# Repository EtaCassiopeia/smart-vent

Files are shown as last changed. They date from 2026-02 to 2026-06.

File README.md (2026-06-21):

# smart-vent

Per-room HVAC vent control. Each vent has a small XIAO ESP32-C6 board driving an SG90
hobby servo that opens or closes a louver. The board joins a Thread mesh hosted by a
Raspberry Pi and exposes itself as a Matter **Window Covering** device. Home Assistant
runs on the same Pi and is the user-facing controller — you toggle the vent in the HA UI
or in a HA automation, and the command travels over Matter-over-Thread to the device,
which moves the servo.

The project is **Matter-over-Thread only**. There is no Wi-Fi path on the device, and no
cloud dependency. The Pi is the entire backend.

## Hardware

| Role | Part | Notes |
|---|---|---|
| Hub | Raspberry Pi (any model with USB) | Runs three Docker containers: OTBR, matter-server, Home Assistant |
| Thread radio | SMLIGHT SLZB-07 USB dongle | CP210x USB-UART (`10c4:ea60`), enumerates as `/dev/ttyUSB0`. Used by OTBR as the Thread Radio Co-Processor |
| Vent MCU | Seeed XIAO ESP32-C6 | RISC-V chip with built-in 802.15.4 and BLE radios. Enumerates as `/dev/ttyACM0` (`303a:1001`) when plugged **directly** into the Pi — not through a USB hub |
| Actuator | SG90 servo | Signal on GPIO2 (XIAO D2 pin). 90° = vent closed, 180° = vent open |

## Architecture at a glance

```
   ┌─────────────────────── Raspberry Pi ──────────────────────────┐
   │                                                                │
   │  Home Assistant ── (WebSocket) ──► matter-server               │
   │       (:8123)                       (:5580)                    │
   │                                        │ BLE pairing           │
   │                                        ▼                       │
   │                                     BlueZ ─── (host BT)        │
   │                                        │                       │
   │                                        │ Matter ops over IPv6  │
   │                                        ▼                       │
   │                                     OTBR (OpenThread Border    │
   │                                           Router container)    │
   │                                        │                       │
   │                                        │ Thread (802.15.4)     │
   └────────────────────────────────────────┼───────────────────────┘
                                            │  ▲
                                  via SLZB-07 USB dongle
                                            │  │
                              ┌─────────────▼──┴────────────┐
                              │   XIAO ESP32-C6 (vent N)    │
                              │   Rust firmware + esp-matter│
                              │   GPIO2 ─► SG90 servo       │
                              └─────────────────────────────┘
```

## Where to look

- **[docs/handbook.md](docs/handbook.md)** — what the system is, how it works, why
  it's built the way it is. Read this top-to-bottom once. Covers Matter, Thread,
  the Pi services, the firmware internals, what happens during commissioning and
  on every replug.
- **[docs/runbook.md](docs/runbook.md)** — step-by-step procedures for **developers**.
  How to set up the Pi from scratch, build the firmware, flash a new vent, commission
  it via HA, assign it to a room. Plus a symptom-driven troubleshooting matrix.
- **[docs/provider-runbook.md](docs/provider-runbook.md)** — step-by-step for
  **providers** assembling kits to ship to clients. Uses the
  `smart-vent-provision` CLI end-to-end: bake the SD card, flash + capture N
  vents, print stickers + quick-start, pack and ship. No source builds.
- **[docs/mobile-api.md](docs/mobile-api.md)** — API contract the smart-vent mobile
  app builds against (matter-server WS, HA REST, mDNS).
- **[docs/mobile-app-spec.md](docs/mobile-app-spec.md)** — screen-by-screen spec
  the Flutter team works from.

## Repo layout

```
firmware/
  vent-controller/                 ESP32-C6 firmware (Rust + ESP-IDF v5.2.3)
    src/                           Rust modules: main, matter, servo, state, identity, ...
    components/esp_matter_bridge/  C++ shim over esp-matter SDK
    sdkconfig.defaults             Non-default ESP-IDF kconfig
    partitions.csv                 nvs / phy_init / 3 MB factory app layout
  shared-protocol/                 vent-protocol crate (CBOR types, angle constants)
docs/
  handbook.md                      Conceptual reference
  runbook.md                       Step-by-step procedures
homeassistant/                     Example HA configs (scripts, automations,
                                   schedule helpers, Lovelace dashboard) for
                                   room/floor grouping and scheduling. Copy
                                   into ~/homeassistant/. See runbook §7.5.
tools/
  scripts/                         setup_otbr.sh, setup_ha.sh — reference Pi bring-up
  qr-generator/                    Renders printable QR PNGs from the boot-logged Matter payload
```

## Status

All firmware code lives on the `feature/matter-over-thread` branch. One vent has been
fully commissioned and verified end-to-end (HA → Close button → servo turns to 90°,
HA → Open → servo turns to 180°). The same firmware image can be flashed onto any
number of XIAO ESP32-C6 boards to add more vents — see the runbook.

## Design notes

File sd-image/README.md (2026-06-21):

# SD card image bake

Workstream C of the deployment plan: bake a Raspberry Pi OS image that
contains the smart-vent runtime, the systemd units, the first-boot
wizard, and the seeded HA config — so the provider can `dd` it to an
SD card and ship.

The bake re-uses `pi/install.sh` against a Raspberry Pi OS Lite
chroot. install.sh is the single source of truth for the layout —
there is no parallel "what the SD image contains" definition.

## Layout

```
sd-image/
  config                              pi-gen build config (IMG_NAME, stage list, …)
  stage-smart-vent/
    prerun.sh                         rsync the repo into the chroot at /usr/src/smart-vent
    EXPORT_IMAGE                      marker telling pi-gen to export an .img from this stage
    00-install/
      00-run-chroot.sh                run install.sh inside the chroot
```

## How CI uses this

`.github/workflows/sd-image.yml` (added alongside this directory)
on a `hub-v*` tag or manual dispatch:

1. Checks out smart-vent at the tag.
2. Clones [pi-gen](https://github.com/RPi-Distro/pi-gen) into the runner.
3. Drops our `config` and `stage-smart-vent` into pi-gen's tree.
4. Runs pi-gen inside Docker (ARM emulation via QEMU binfmt).
5. Captures `deploy/*.img.xz` + sha256, uploads as a release asset.

Expected runtime on `ubuntu-latest`: ~30–60 min cold.

## How to bake locally (if you have ~30 min and Docker)

```bash
git clone --branch 2026-06-18-raspios-bookworm-arm64 \
  https://github.com/RPi-Distro/pi-gen
cd pi-gen
cp ../smart-vent/sd-image/config ./config
cp -r ../smart-vent/sd-image/stage-smart-vent ./
# Stage the smart-vent source where prerun.sh can find it. build-docker.sh
# only mounts the pi-gen tree into the build container, so we co-locate.
rsync -a \
  --exclude '.git/' \
  --exclude 'firmware/vent-controller/target/' \
  --exclude '**/__pycache__/' --exclude '**/.venv/' \
  ../smart-vent/ stage-smart-vent/src/
echo 'export SMART_VENT_VERSION=dev' >> config
sudo CONTINUE=1 ./build-docker.sh
ls deploy/
```

## Why pi-gen, not packer / nspawn / etc

pi-gen is the official Raspberry Pi tooling, knows the exact partition
layout / bootloader / firstrun.sh shape Pi OS expects, and is what
upstream Raspberry Pi OS releases are built with. Less surprise on
boot.

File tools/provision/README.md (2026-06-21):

# smart-vent-provision

Provider-side CLI for prepping smart-vent kits.

## Phases — separate by design

This tool is responsible for the **provider** workflow: writing firmware
to boards and gathering the artifacts needed to print stickers for each
vent. It does **not** commission anything. Commissioning (pairing a vent
to a Matter fabric and assigning it to a room) is the **client's** job,
done from the smart-vent mobile app at install time.

| Phase | Owned by | Tool | Effect |
|---|---|---|---|
| Flash | Provider | `smart-vent-provision flash` | Writes firmware to the ESP32-C6 via `espflash`. Nothing else. |
| Capture | Provider | `smart-vent-provision capture` | Reads the post-boot serial log, records each board's EUI-64 / Matter QR / pairing code into a per-kit `inventory.json`. |
| Label | Provider | `smart-vent-provision labels` | Renders an Avery 5160 sticker sheet from the inventory. Sticker goes on the physical vent. |
| Quick-start | Provider | `smart-vent-provision kit-card` | Renders the one-page card that ships in the box. |
| SD image | Provider | `smart-vent-provision image` | Pulls the hub `.img.xz` from the latest `hub-v*` GitHub release, sha256-verifies it, and `xz \| dd`s it onto the SD card. |
| **Commission** | **Client** | **smart-vent mobile app** | **Scans the sticker QR, pairs the vent into the client's HA fabric, picks the room/floor.** |

The mobile app is a separate project (Flutter, single codebase for
Android + iOS). It talks to the client's hub via `matter-server`'s
WebSocket API and HA's REST API. It is not part of this CLI.

## Install

The CLI is published as a Python wheel via the repo's release pipeline.
Until that wheel lands, install from this repo:

```bash
cd tools/provision
pip install --user -e .

# Optional dev deps for running the tests:
pip install --user -e ".[dev]"
```

External dependency: **espflash** must be on `PATH`.

```bash
cargo install espflash --version '^3'
```

## Usage

### Flash a board (just the firmware bits)

```bash
# Single board
smart-vent-provision flash

# Several in a row
smart-vent-provision flash --count 6
```

The CLI prompts you to BOOT-hold + replug, then runs espflash. Repeat
for as many boards as `--count`. No inventory is written.

### Capture a board's identity for the sticker

After flashing, power-cycle the board (NO BOOT hold) so it emits a
fresh boot banner, then:

```bash
smart-vent-provision capture --kit-id kit-acme-2026-06-001
# optional cosmetic hint (purely what gets printed on the sticker)
smart-vent-provision capture --kit-id kit-acme-2026-06-001 --label-hint 'study'
```

This reads `/dev/ttyACM0` for up to 45s, pulls the EUI-64, Matter QR
payload, and manual pairing code from the boot log, and appends to
`./kits/<kit-id>/inventory.json`.

### Flash + capture in one walk (convenience)

```bash
smart-vent-provision batch --count 6 \
  --kit-id kit-acme-2026-06-001 \
  --label-hints 'living room,living room,study,study,bedroom 1,basement'
```

Walks: BOOT-hold prompt → flash → power-cycle prompt → capture, for
each of N boards. The label-hints are purely cosmetic printed text;
they do **not** assign vents to rooms.

### Print stickers + client card

```bash
smart-vent-provision labels   --kit kit-acme-2026-06-001  # -> labels.pdf
smart-vent-provision kit-card --kit kit-acme-2026-06-001 \
  --ap-password 'changeMe' --support-contact 'help@smart-vent.example'
```

### Write the SD card

```bash
# Pulls the latest hub-v* GH release, sha256-verifies, dd's onto /dev/sdb.
sudo smart-vent-provision image --device /dev/sdb

# Pin to a specific tag instead of latest:
sudo smart-vent-provision image --device /dev/sdb --hub-tag hub-v0.1.0
```

Refuses to write to anything that isn't a whole-disk block device
(catches the common `/dev/sdb1` partition mistake) and prompts for
confirmation before clobbering the device. `--yes` skips the prompt
for automation. Needs `xz` and `dd` on `PATH` — both ship in any
Debian/Ubuntu base install.

## Inventory schema

```json
{
  "kit_id": "kit-acme-2026-06-001",
  "firmware_version": "firmware-v0.1.0",
  "hub_image_version": "",
  "vents": [
    {
      "eui64": "58:e6:c5:01:0a:dc",
      "qr": "MT:Y3.13OTB00KA0648G00",
      "manual_code": "34970112332",
      "label_hint": "study"
    }
  ]
}
```

Hand-editable. Fix typos, add cosmetic hints, reorder before printing.
`label_hint` is **just sticker text** — the client app decides the
actual room during commissioning.

## Limitations (v1)

- One board at a time. No parallel flash jig (BOOT-hold is still
  manual). Operator target: <30 s/board after the first.
- `image` subcommand (write SD card) deferred — depends on the Pi hub
  SD image, which is the next workstream.
- Per-vent unique Matter passcodes deferred to v2 (per-device factory
  NVS partitions via `mfg_tool`). v1 uses the SDK default passcode.

## Tests

```bash
pytest tools/provision/tests -q
```

No hardware needed — release fetch is mocked, label/QR rendering is
deterministic.

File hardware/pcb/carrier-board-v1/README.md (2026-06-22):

# Battery carrier board — v1 assets

Generated assets for the NiMH battery carrier PCB. See
[`docs/battery-carrier-board.md`](../../../docs/battery-carrier-board.md) for
the design writeup, BOM, layout rules, and current status (schematic
validated, footprint placement collision-checked and fixed, routing not
yet done).

**Two variants**: the status LED is optional (see the doc's §2a for the
tradeoff — locate/status feedback vs. a small continuous idle draw on the
3V3 rail plus a tighter placement). Both are generated from the same
`smart_vent_board.py`; pick whichever matches your build.

| File | What it is |
|---|---|
| `smart_vent_board.py` | Circuit as code (SKiDL). Source of truth — edit this, re-run, re-import. `python3 smart_vent_board.py` regenerates `smart_vent.net` (with LED); `SMART_VENT_LED=0 python3 smart_vent_board.py` regenerates `smart_vent_no_led.net` (without). Requires `pip install skidl`. |
| `smart_vent.net` | KiCad netlist, with-LED variant. Import via Pcbnew → File → Import → Netlist. |
| `smart_vent_no_led.net` | KiCad netlist, no-LED variant. |
| `smart_vent_floorplan.svg` | Original placement *concept* diagram (component zones, power-loop routing, ground star point). The zoning (left=signal, right=power, bottom=connectors) is still accurate; the exact part positions drawn here are not — they predate fitting real footprint sizes and were superseded by the collision-free coordinates in `kicad-project/` and `place_smart_vent.py`. Treat this SVG as illustrating the *idea*, not the final layout. |
| `place_smart_vent.py` | Run from KiCad's Pcbnew scripting console (after netlist import + footprint assignment) to auto-place all footprints per the floorplan, draw the 45×34 mm board outline, and add mounting holes. Works for either variant — it skips refs that aren't present (D1/R7/C5 on the no-LED import). |
| `smart_vent_bench_sheet.pdf` | One-page printable BOM + assembly order + smoke test, for the with-LED bench build. |
| `firmware-reference/power_indicator.rs` | Mirror of `firmware/vent-controller/src/carrier_board.rs` — the real module now lives in the crate (behind the `battery-carrier-board`/`led-indicator` Cargo features) and is the source of truth; this copy is kept for browsing without cloning the firmware build. Verified building on `riscv32imac-esp-espidf` against the crate's pinned `esp-idf-hal`; not yet called from `main()` or flashed (see #47). |
| `kicad-project/` | Placement-checked `.kicad_pcb` (zero shorts/overlaps/clearance violations, not yet routed) + `.kicad_pro` projects + DRC reports + the `nudge_apart.py` solver, for both variants — see its own README. |

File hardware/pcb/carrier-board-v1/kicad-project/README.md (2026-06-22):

# KiCad project — placement clean, NOT routed, NOT fab-ready

Two boards here, one per LED variant (see
[`docs/battery-carrier-board.md` §2a](../../../../docs/battery-carrier-board.md#2a-led-indicator-optional)
for the tradeoff):

| | With LED | Without LED |
|---|---|---|
| Board | `smart_vent_v1.kicad_pcb` | `smart_vent_v1_no_led.kicad_pcb` |
| Project | `smart_vent_v1.kicad_pro` | `smart_vent_v1_no_led.kicad_pro` |
| DRC report | `drc_report.json` | `drc_report_no_led.json` |
| Build with | `python3 build_board.py` | `SMART_VENT_LED=0 python3 build_board.py` |

Each `.kicad_pcb` has a matching `.kicad_pro` — open that (or just the
`.kicad_pcb` directly, KiCad doesn't require the project file to open a
board standalone) so the net-class trace/via widths from
[§5](../../../../docs/battery-carrier-board.md#5-board-layout-rules)
persist between sessions instead of resetting to defaults: `Default`
(signals) at 0.25mm track / 0.5mm via, `Power` (VBAT, VBAT_RAW, SERVO_VCC,
GND) at 0.9mm track / 0.6mm via. The project files were hand-built from
KiCad's blank template (`pcbnew` scripting doesn't expose project creation)
— if KiCad ever rewrites them on save, that's expected and fine.

Both were generated by `build_board.py` (run against KiCad 10.0.4's bundled
`pcbnew` Python module — see the script for how to invoke it; it bypasses
the GUI-only netlist-import step, which modern KiCad no longer exposes to
scripting). It loads real footprints from KiCad's stock libraries where one
exists, places everything at resolved, collision-free coordinates (see
below), and wires nets per `../smart_vent_board.py`'s connectivity.
**No copper has been routed on either.**

## Placement: resolved (issue #46's DRC findings are fixed)

The original floorplan (`smart_vent_floorplan.svg`) got the *zoning* right
— left=signal, right=power, bottom=connectors — but the exact coordinates
didn't account for real footprint courtyard sizes, and at actual sizes
several parts collided: the THT slide switch substitute for SW1 (10.37mm
wide — much bigger than the small SMD pushbutton the floorplan was sized
around) and the THT radial cap substitute for C2 (8.59mm round, vs. the
small SMD electrolytic originally planned) were the two biggest culprits.

`nudge_apart.py` solves this: it builds the board, finds every pair of
overlapping courtyards (using real, post-rotation courtyard geometry), and
iteratively pushes them apart along whichever axis needs the smaller move,
holding U1/J2/the left analog cluster (R4/R5/R6/C1) fixed since they had no
DRC findings. It converges to the coordinates now hardcoded in
`build_board.py`'s `PLACE` dicts. One footprint needed a manual follow-up
the solver doesn't know about: **J2** (the servo header) had its last pad
landing past the board's bottom edge entirely at its original anchor
position (the footprint's "position" is pad 1, not its geometric center —
a 3-pin 2.54mm-pitch vertical header's last pad sits 5.08mm away from that
anchor) and separately collided with **U1**'s placeholder footprint, which
is a tall thin single-column header utterly unrepresentative of the real
XIAO module's shape (see #45) — J2 ended up shifted sideways in x to clear
U1's column, then up in y to clear the board edge by the required 0.5mm.

Re-running DRC after these fixes, on both variants:

| | With LED (before → after) | Without LED (before → after) |
|---|---|---|
| Shorts | 3 → **0** | 1 → **0** |
| Clearance violations | 1 → **0** | 1 → **0** |
| Courtyard overlaps | 8 → **0** | 5 → **0** |
| Board-edge clearance | (masked by the above) → **0** | (masked by the above) → **0** |

What's left in `drc_report*.json` is purely cosmetic: silkscreen reference
labels overlapping each other or clipped by the board edge/solder mask —
normal for default-placed footprint text once parts are packed this
tightly, fixed by dragging labels in the PCB editor, not a routing or
electrical concern.

## Footprints with no exact stock match (placeholders, need sourcing — issue #45)

**C2 is resolved** — `Capacitor_SMD:CP_Elec_6.3x5.4` exists after all; the
first pass's library search missed it (it's filed under
`Capacitor_SMD.pretty`, not a separate electrolytic library). It's now the
real footprint on both boards (courtyard 9.69×7.19mm — similar area to the
THT stand-in it replaced, not smaller as originally assumed; needed one
follow-up nudge to R2 to clear a new, smaller overlap once the real shape
went in). Two placeholders remain:

| Ref | Part | Stand-in used | What's actually needed |
|---|---|---|---|
| U1 | Seeed XIAO ESP32-C6 | generic 1×7 pin header | The official Seeed XIAO footprint (KiCad's stock libraries only ship `MCU_Seeed_ESP32C3`, not the XIAO carrier module). Source from Seeed's own KiCad library or via `easyeda2kicad` against the LCSC part. Its odd placeholder shape is also why J2 needed the manual nudge above — expect to revisit J2's exact position once the real footprint lands. |
| J1 | "SM-2P" battery connector | generic 1×2 pin header | The hobby-RC "JST-SM" 2-pin plug is not a real JST series (despite the name) and isn't in KiCad's `Connector_JST.pretty` (checked `JST_PH`/`JST_VH`/`JST_GH` series specifically — none match). Needs a footprint sourced from the connector's actual datasheet/LCSC listing (e.g. via `easyeda2kicad` against a specific part number once you've picked the exact connector to buy), or substitute a connector that *is* in-library and adjust the BOM. |

## What's left (tracked in #46)

Placement is clean; routing is not done. Next: route to the five rules in
[`../../../../docs/battery-carrier-board.md` §5](../../../../docs/battery-carrier-board.md#5-board-layout-rules)
(fat traces on the servo power loop, single star ground, etc.), apply the
net classes from the `.kicad_pro` files, run DRC again (should stay clean
on the electrical/courtyard front; clean up the cosmetic silkscreen
overlaps while you're in there), then plot Gerbers per §6.

## Gerbers (pipeline validation only — see the warning in each folder)

`gerbers-unrouted-with-led/` and `gerbers-unrouted-no-led/` are committed
Gerber + drill exports of these same two boards. **Do not send these to a
fab** — there's no copper routed, even though placement is now clean. They
exist to confirm the export pipeline produces the JLCPCB-compatible layer
set documented in the main doc's §6; each folder has its own README
repeating this warning and the exact `kicad-cli` commands used to generate
it, so they're trivially reproducible rather than load-bearing artifacts.

To regenerate either (or once a board is actually routed):

```bash
kicad-cli pcb export gerbers --output <dest>/ <board>.kicad_pcb
kicad-cli pcb export drill   --output <dest>/ <board>.kicad_pcb
```

Once routing is done, replace these with the actual fab-ready output and
drop "unrouted" from the directory names.

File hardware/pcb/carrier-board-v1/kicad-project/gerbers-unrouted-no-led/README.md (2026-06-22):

# DO NOT SEND TO A FAB

These Gerbers + drill file were plotted from `../smart_vent_v1_no_led.kicad_pcb`,
which now has a collision-free placement (see issue #46 — all shorts,
clearance violations, and courtyard overlaps are resolved) but **still has
no copper routed**. They exist solely to confirm the fab-export pipeline
itself works and produces the JLCPCB-compatible layer set documented in
[`docs/battery-carrier-board.md` §6](../../../../../docs/battery-carrier-board.md#6-fab-settings-jlcpcb)
— that is the only thing they verify.

Regenerate after routing with:

```
kicad-cli pcb export gerbers --output gerbers-unrouted-no-led/ ../smart_vent_v1_no_led.kicad_pcb
kicad-cli pcb export drill   --output gerbers-unrouted-no-led/ ../smart_vent_v1_no_led.kicad_pcb
```

(swap in the routed board path once routing is done, and rename the output
directory to drop "unrouted").

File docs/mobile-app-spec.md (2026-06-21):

# smart-vent mobile app — spec

> **Status: deferred / reference only.** As of v1, smart-vent vents
> commission via the Home Assistant Companion app out of the box —
> client scans the QR sticker on each vent, picks a room, done. A
> custom branded app duplicates the HA app's commissioning flow
> without adding engineering value; the only reasons to build one
> are branding or a streamlined onboarding UX for non-technical
> clients. This document remains as the contract a future
> branded-app effort would target. The companion contract document
> [`mobile-api.md`](mobile-api.md) is useful regardless — it
> describes what any integration (custom app, automation script,
> third-party tool) would talk to.

The smart-vent mobile app, **if built**, would be the
**client-facing** half of the deployment plan (workstream 6). It
would live in a separate Flutter repo (`smart-vent-app`, not in this
repo); this document defines what it needs to do. The API contract
it would build against is in [`mobile-api.md`](mobile-api.md).

## Audience + scope

The app is for the **end client**, not the provider. The provider
uses `smart-vent-provision` to prep kits; the client uses the app
to turn a freshly delivered kit into a working installation.

The app handles three things:

1. Pair the phone to the user's hub (mDNS discovery + HA token).
2. Add each vent to the user's home: scan QR sticker, the hub
   commissions it, the user picks a room.
3. Day-2: a thin "control my vents" surface so a user can open/
   close a vent without opening HA. (HA is still available; we just
   want one-tap control for non-techy users.)

Anything more complex than that — automations, advanced configuration,
multi-user sharing — happens in HA's own app. We don't reimplement
HA.

## Why Flutter + WS-API approach

The phone **does not** run a Matter SDK. The Pi does. Concretely:

- The phone is on the home WiFi.
- The Pi has BLE and 802.15.4 radios; it's the Matter controller.
- The app sends JSON to `ws://<hub>:5580/ws` and HA's REST.

This was the major decision documented in the design plan
(workstream 6.1). The trade-off: the Pi must be within BLE range
(~10 m) of each vent during commissioning. That's fine because OTBR
needs the Pi central in the house anyway.

Flutter is the single-codebase choice (Android + iOS); no platform
forks.

## Screen-by-screen flow

### Screen 0 — Welcome / discovery

- Logo, "Get started" button.
- On tap, browse mDNS for `_smart-vent._tcp.local.`.
- If one hub found, auto-select it. If multiple, list them with
  TXT-record version. If none, "Enter hub address" manual input.
- "Where do I find this?" link → kit-card photo with the AP
  SSID/password shown.

### Screen 1 — HA token

- "We need to connect to your hub" panel.
- "Sign in to Home Assistant" button → opens HA's OAuth flow in a
  WebView at `http://<hub>:8123/auth/authorize?...`.
- On callback, store the long-lived access token in
  keychain/keystore. Verify with a `GET /api/` ping.

### Screen 2 — Home

After auth, the home screen shows:

- A list of already-commissioned vents (from `get_nodes` →
  filter for WindowCovering), grouped by HA Area.
- Per vent: name, room, current position (% open), open/close
  buttons.
- Floating "+" button → **Add a vent** (Screen 3).
- Top-right gear → settings (re-auth, change hub, factory reset).

### Screen 3 — Add a vent

- "Point at the sticker" camera viewport.
- Auto-detect Matter QR (the `MT:...` prefix). Once detected:
  vibrate, show a "Pair this vent?" confirmation with the last 4
  of the EUI (from the sticker).
- On confirm: full-screen progress card. Streams matter-server's
  WS events:
  1. "Connecting over Bluetooth…" (PASE)
  2. "Sending Thread credentials…" (push)
  3. "Confirming…" (CASE)
- On failure: show the error code from
  [`mobile-api.md`](mobile-api.md#commission_with_code) verbatim
  + a one-line plain-English explanation + "Try again" button.
- On success: → Screen 4.

### Screen 4 — Place this vent

- "Which room is this vent in?"
- Picker reads existing HA Areas. Below the picker: "+ New room"
  → name input, optional Floor picker (or "+ New floor").
- "Optional: give this vent a name" text field. Defaults to the
  next-free `<room>-vent-<n>` slot.
- Continue → calls HA WS:
  1. Create the Area + Floor if needed
  2. Set the cover entity's `area_id`
  3. Rename the entity to `cover.<room>_vent_<n>` (slugified)
- → Screen 5.

### Screen 5 — Test the vent

- "Let's make sure it works." Big "Open" + "Close" buttons.
- On tap: `device_command` to the WindowCovering cluster. Watch
  for the position attribute to update; show the new position.
- "Done" button → back to Home (Screen 2) with the new vent
  listed.

### Screen 6 — Per-vent control (from Home, tap a vent)

- Cover entity name + room.
- Big position slider (0-100%).
- "Open", "Close", "Set to 50%" quick buttons.
- "Rename" / "Move to another room" / "Remove vent" overflow menu.
- "Identify" button → calls Matter Identify cluster, vent wiggles.

### Screen 7 — Settings

- Hub: name, version (from mDNS TXT), "Switch hub" button.
- Account: HA user email, "Sign out" (clears token).
- About: app version, contract version, link to docs.
- "Factory reset" — clears the keychain entry and returns to
  Screen 0.

## State-management notes (for the implementer)

- Cache `get_nodes` for ~30s; refresh on focus.
- Stream live position updates via matter-server's subscription
  mechanism (`start_listening` then attribute-changed events) for
  the Home screen and per-vent screen.
- WS reconnection: exponential backoff, max 60s. Show a
  non-blocking "Reconnecting…" banner; don't gate the UI.
- Token refresh: HA's long-lived token doesn't expire (by design).
  No refresh dance needed.

## Branding hooks

Provider can ship a white-labeled build by overriding:

- `assets/logo.svg`
- `lib/theme.dart` — primary color, accent, dark variant
- `strings.arb` — support email, app name

These are pulled at build time from `--dart-define` flags so the
same CI workflow produces both a default build and per-provider
builds.

## Out of scope (for v1)

- Multi-fabric / Apple Home commissioning. Matter spec supports
  multi-admin handoff; we punt it to v2.
- In-app firmware updates for vents. OTA needs the Matter
  OTAProvider cluster which we don't ship yet.
- iPad / tablet-specific layouts. Phone-first for v1.
- Notifications (filter clean reminders etc.). v2 once we figure
  out a sensor strategy.

## Build + ship

- iOS: TestFlight for beta, App Store for GA. Apple developer
  account is the provider's responsibility.
- Android: GitHub Releases for `.apk` sideloads, Play Store for GA.
- Same versioning scheme as the rest of the project (`app-vX.Y.Z`).

## Contract changes

If the hub side (matter-server commands, HA WS messages, mDNS TXT
shape) needs to change in a way that breaks older app builds, the
hub bumps its `_smart-vent._tcp.local.` TXT `version` field to a
new major. The app shows a "your hub is newer than this app, please
update" screen and refuses to commission. Provider then ships an
app update.

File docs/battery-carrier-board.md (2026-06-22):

# Battery carrier board (NiMH) — design notes

> **Status: schematic/netlist validated, placement clean, board not yet
> routed.** This document covers an alternative power path for a vent:
> running off a 4-cell NiMH pack instead of USB, via a small carrier PCB.
> The circuit (parts, values, nets) is done and machine-verified;
> footprint placement has been collision-checked and fixed (zero shorts/
> overlaps/clearance violations on both variants); routing/Gerbers are
> not done. See [Current state](#current-state) for exactly what exists
> and what's left.
>
> **Two variants, pick one**: the status LED (§2a) is optional. Both a
> with-LED and a no-LED build are generated from the same source and
> tracked side by side — the no-LED variant trades away locate/status
> feedback for a lower idle power draw.

This is a variant of the wiring in [handbook.md §3](handbook.md) (XIAO +
SG90 over USB power). Use this doc instead of the handbook's wiring table when
building a battery-powered vent.

## 1. Why a carrier board, and why NiMH

The target battery is a 4.8 V, 2-cell-pack-of-2 (4-cell) **NiMH** RC pack,
1000 mAh, with an SM-2P plug. Two things made a custom PCB worth it over
hand-wiring:

- The XIAO ESP32-C6's onboard charge controller only charges a single-cell
  3.7 V **LiPo** on its `B+`/`B-` pads (4.2 V CC/CV termination). Feeding a
  4.8 V NiMH pack into those pads charges the wrong chemistry at the wrong
  voltage — **never wire this pack to `B+`/`B-`.** Also, per Seeed's docs,
  the `5V` pin carries no voltage when running off `B+`/`B-`, so that path
  can't power the servo either.
- NiMH in-circuit charging needs a real smart-charger IC (MAX712/713,
  LTC4060, BQ2002-class) with −ΔV/dT-dt/timer termination — not a $1
  TP4056-style part. Ready-made modules for this are rare and bulky.

Given the pack already ships with a swappable SM-2P plug, the pragmatic
design is: **charge externally on a NiMH/RC charger, make the pack
removable, and let the board do power distribution + battery monitoring
only.** No charge circuit on the board — that's what keeps it a trivial
2-layer job.

The NiMH voltage range (5.6 V fresh → 4.0 V empty) is actually a *better*
match for the SG90 servo (happy 4.0–6.0 V) than the LiPo path the handbook's
USB wiring implies — the servo runs directly off the battery rail, no boost
converter needed.

## 2. Power architecture

```
        SM-2P                 ┌───── SK6812 LED  (status + identify) [OPTIONAL, see §2a]
VBAT ──┤ in ├── master sw ──┬┴── XIAO 5V pin ── onboard LDO ── 3V3 ─→ C6 [+ LED Vdd if fitted]
       └─────┘              │
                             ├── 2M/1M divider ──→ A1 (GPIO1)   [pack voltage sense]
                             │
                             └── P-FET (high-side) ──→ SG90 VCC  [gated by GPIO]
                                     ▲
                              2N7002 level-shift ← GPIO21 (servo_en)

GND ── common (star point at battery return)
GPIO2 ──────────────────────────────→ SG90 signal
```

Three decisions that depart from the handbook's USB wiring and from Seeed's
own reference design:

1. **A plain SPST master switch on VBAT, not a power-mux IC.** A
   freshly-charged "4.8 V" NiMH pack actually sits around 5.6 V — above USB's
   5 V and at the edge of most auto-switch ICs' (TPS2113/LTC4412) comfortable
   range. A slide switch in the VBAT line sidesteps that entirely: off to
   flash over USB (battery fully isolated), on to deploy. Zero quiescent loss,
   no edge cases.
2. **A 1:3 sense divider, not 1:2.** Seeed's reference divider assumes a
   4.2 V LiPo max (→2.1 V at the ADC). This pack hits 5.6 V, and the C6 ADC's
   linear range tops out around ~2.45 V. A 1:2 divider would clip at full
   charge; 2 MΩ (top) / 1 MΩ (bottom) keeps both ends (5.6 V→1.87 V,
   4.0 V→1.33 V) inside the linear range, at ~1.9 µA drain.
3. **The servo is power-gated**, not left continuously powered. This is the
   single biggest battery-life lever: an SG90 idles at ~10 mA, which alone
   would drain the 1000 mAh pack in ~4 days. A high-side P-FET (driven through
   a 2N7002 so the 3.3 V GPIO gets a full gate swing) cuts servo power to
   ~0 mA between moves; it only draws during the ~0.5 s travel. Combined with
   an on-demand LED and a tuned Thread SED poll period, expected runtime goes
   from days to roughly 2–3 weeks per charge.

If your louver back-drives under its own weight (i.e. it doesn't hold
position by friction alone once power is cut), leave `servo_en` asserted
instead — one line of firmware, at the cost of ~10 mA continuous draw.

## 2a. LED indicator (optional)

The status LED (D1, plus R7/C5) is **optional** — omit it for the
lowest-drain, lowest-part-count build. The tradeoff:

- **Cost while fitted**: the SK6812's `VDD` is wired directly to the 3V3
  rail (not power-gated like the servo), so the LED IC's own idle/listening
  current draws continuously whenever the board is powered — small per the
  datasheet (sub-mA), but nonzero, on top of whatever it draws during the
  brief on-demand blinks described in §8. Over weeks on a 1000 mAh pack,
  "small but always-on" is exactly the kind of draw the rest of this design
  goes out of its way to avoid (see the servo power-gating discussion above).
- **What you lose without it**: physically locating a specific vent among
  several installed ones (the LED's primary job, see §8), and the
  install/pairing/command-result/battery-state feedback that rides on the
  same LED. None of this is safety-critical — the vent still opens/closes,
  reports state to Matter/HA, and (per #50) can still drive a low-battery
  *notification* in Home Assistant without any physical LED at all, since
  that path goes through the Matter Power Source cluster, not the indicator.
- **What it's worth keeping for**: if you're deploying more than a couple of
  vents, "which physical vent is this" stops being obvious without it.
  Single-vent builds have the least to gain from fitting it.

Both variants are generated from the same source and tracked side by side:

| | With LED | Without LED |
|---|---|---|
| Netlist | `smart_vent.net` | `smart_vent_no_led.net` |
| Generate | `python3 smart_vent_board.py` | `SMART_VENT_LED=0 python3 smart_vent_board.py` |
| Placement-checked board | `kicad-project/smart_vent_v1.kicad_pcb` | `kicad-project/smart_vent_v1_no_led.kicad_pcb` |
| Parts omitted | — | D1 (SK6812), R7 (470Ω data series), C5 (100nF decouple) |
| GPIO22 | wired to LED_DIN | unconnected, free for future use |
| DRC findings (placement, unrouted) | clean — 0 shorts/overlaps/clearance | clean — 0 shorts/overlaps/clearance |

Dropping the LED originally also resolved most of the worst placement
cluster DRC found in issue #46 (D1/C2/C3/C5/R7 were the tightest corner of
the floorplan) — that issue's full set of findings (on both variants) has
since been resolved by re-spacing the placement; see §9 and
`kicad-project/README.md` for how. The LED-vs-battery-life tradeoff above
stands regardless of the placement fix.

A future middle ground — power-gating the LED's `VDD` through its own
small load switch, the same way the servo is gated — would close the
"always-on idle draw" gap without removing the feature, at the cost of one
more GPIO + transistor. Worth revisiting if the with-LED variant turns out
to be popular; not done here since the ask was a clean on/off choice.

## 3. Connection map

| XIAO pin | GPIO | Net | Purpose |
|---|---|---|---|
| 5V | VBUS | VBAT (via master switch) | board power in |
| 3V3 | — | V3V3 | SK6812 Vdd **(optional, see §2a)** |
| GND | — | common / star ground | |
| D2 | GPIO2 | SERVO_SIG | servo signal (existing — same pin the handbook's USB build uses) |
| D1 / A1 | GPIO1 | VBAT_SENSE | divider tap, pack voltage sense |
| D3 | GPIO21 | SERVO_EN | → 2N7002 gate (via 1k) |
| D4 | GPIO22 | LED_DIN **(optional)** | → SK6812 data (via 470Ω), unconnected/free if the LED is omitted |

GPIO2 matches the existing firmware's servo pin
(`firmware/vent-controller/src/main.rs`); GPIO1/21/22 are unused by the
current build, so this slots in without conflicts.

## 4. Bill of materials

Core (both variants):

| Ref | Value / part | Footprint | Note |
|---|---|---|---|
| U1 | XIAO ESP32-C6 | Seeed XIAO module, 14-pin | socketed (female headers), not soldered down; **verify pad order against the official Seeed footprint before routing** |
| J1 | SM-2P battery header | JST-SH-compatible 2-pin | battery in |
| J2 | 1×3 pin header, 2.54 mm | — | SG90: SIG · VCC · GND |
| SW1 | SPST slide switch, ≥1 A | — | master power |
| Q1 | AO3401A (P-MOSFET, −30 V) | SOT-23 | servo high-side gate; **verify G/S/D = 1/2/3 against the datasheet** |
| Q2 | 2N7002 (N-MOSFET) | SOT-23 | gate level-shift; same pinout caveat |
| R1, R3 | 100 kΩ ×2 | R_0603 | P-FET gate pullup / N-FET gate pulldown |
| R2 | 1 kΩ | R_0603 | GPIO → N-FET gate series |
| R4 | 2 MΩ | R_0603 | divider top |
| R5 | 1 MΩ | R_0603 | divider bottom (1:3 → A1) |
| R6 | 330 Ω | R_0603 | servo signal series |
| C1, C3 | 100 nF ×2, X7R | C_0603 | sense tap / servo decouple |
| C2 | 470 µF, 10 V, electrolytic (polarized) | CP_Elec_6.3×5.4 | servo bulk cap — mount physically at J2, not at the XIAO |
| C4 | 10 µF, X5R | C_0805 | VBAT bulk |
| — | 2× 1×7 female header, 2.54 mm | — | XIAO socket |
| — | 2× M2.5 screws + standoffs | Ø2.7 mm cutouts | mounting |
| ext | NiMH 4.8 V 1000 mAh pack (SM-2P) + SG90 | — | not on board |

Add-on, only on the with-LED variant (see §2a for the tradeoff):

| Ref | Value / part | Footprint | Note |
|---|---|---|---|
| R7 | 470 Ω | R_0603 | LED data series |
| C5 | 100 nF, X7R | C_0603 | LED decouple |
| D1 | SK6812 RGB LED (5050), **not WS2812B** | SK6812 PLCC4 | locate + battery-state indicator; WS2812B's logic threshold is marginal at 3.3 V, SK6812 is reliable; **verify VDD/DOUT/GND/DIN = 1/2/3/4** |

The three "verify" callouts above are the only things that need eyes before
routing — a wrong pin order on any of them silently miswires the board.

## 5. Board layout rules

The board is 45×34 mm, 2-layer, 1.6 mm. Floorplan: analog/signal cluster on
the left (near the XIAO's D1–D4 pins), high-current power cluster on the
right (near 5V/GND), servo connector on the bottom edge, LED in the corner
facing outward (so "find this vent" is visible through the enclosure) — only
on the with-LED variant; the no-LED variant simply leaves that corner empty.
`hardware/pcb/carrier-board-v1/smart_vent_floorplan.svg` illustrates this
zoning concept, but its exact part positions are superseded — see §9 and
`kicad-project/README.md` for the actual collision-free coordinates now
in `kicad-project/*.kicad_pcb` and `place_smart_vent.py`.

Five rules that matter more than exact placement:

1. **Keep the servo loop short and fat.** The path battery+ → SW1 → Q1
   (source→drain) → C2 → servo VCC, and back via GND to the star point, is
   the only place real current flows (SG90 stall ≈ 650 mA plus inrush into
   C2). Use 0.8–1.0 mm traces here; everything else can be thin (0.25 mm).
2. **Single star ground at the battery negative.** Route the servo's GND
   return and the divider/LED GND back as separate runs that meet only at
   the star point. If they share copper, servo current spikes corrupt the
   ADC reads.
3. **Keep the sense node compact and quiet.** R4/R5/C1 and the GPIO1 tap
   should sit as a tight cluster over solid ground pour, physically away
   from Q1/C2.
4. **C2 belongs at the servo connector, not near the XIAO.** That's what
   absorbs the SG90's stall-current spike before it sags the rail and
   browns out the C6.
5. **Keep the USB edge and the master switch accessible** — USB-C for
   flashing, the switch reachable without opening the vent enclosure.

Layer plan: parts + signal on top, one uninterrupted GND pour on the
bottom, stitched with vias. Don't let a top-layer trace cut a slot through
the bottom pour under the sense node. Net classes: Power (VBAT, VBAT_RAW,
SERVO_VCC, GND) at 0.9 mm track / 0.6-0.3 mm via; Default (signals) at
0.25 mm track / 0.5-0.3 mm via.

## 6. Fab settings (JLCPCB)

- Layers: 2 · Dimensions: 45×34 mm (from Edge.Cuts) · Thickness: 1.6 mm
- Gerbers: `F.Cu`, `B.Cu`, `F.SilkS`/`B.SilkS`, `F.Mask`/`B.Mask`,
  `Edge.Cuts` — "Protel filename extensions" off
- Drill: Excellon, single file, PTH+NPTH merged
- Surface finish: HASL (free, sufficient — no need for ENIG on this board)
- JLCPCB's defaults (min trace/space 0.127 mm, min hole 0.3 mm, min annular
  ring 0.13 mm) are well inside this design's margins
- Assembly is optional and probably not worth it: ~13 small passives plus 2
  SOT-23s hand-solder faster than dealing with JLCPCB's part-library
  matching for a one-off. Only the XIAO headers and the SM-2P connector are
  through-hole regardless.

## 7. Assembly order and smoke test

Assembly order: flattest SMD passives first (R1–R6, C1, C3, C4, plus R7/C5
if the LED is fitted) → SOT-23s (Q1, Q2 — double-check G/S/D) → D1 if fitted
(watch corner orientation) → C2 electrolytic (stripe = −) → through-hole
parts (J1, J2, SW1) → solder the two female headers → socket the XIAO last
(don't solder it down).

Before powering with the XIAO socketed, with just the bare board + battery:

1. DMM check: no short VBAT↔GND.
2. Pack on, SW1 on → 5V pad reads 4.0–5.6 V; servo-VCC pad reads ≈0 V
   (P-FET off by default — confirms the gate pulldown is working).
3. Insert XIAO → 3V3 pad reads 3.3 V.
4. Flash firmware → expect an identify blink, one servo move, one battery
   read.

A full one-page version of this (with the BOM table) is at
`hardware/pcb/carrier-board-v1/smart_vent_bench_sheet.pdf` — print it for the
bench.

## 8. Firmware integration

**Status: lands in the crate, compiles, behind a feature flag — not yet
called from `main()`, not flashed to real hardware.**
`firmware/vent-controller/src/carrier_board.rs` (mirrored at
`hardware/pcb/carrier-board-v1/firmware-reference/power_indicator.rs` for
reference) is now a real module in the `vent-controller` crate, gated
behind two Cargo features so it has zero effect on the default
always-on-USB build:

- `battery-carrier-board` — the `servo` and `battery` modules below
- `led-indicator` — the `indicator` module, requires `battery-carrier-board`

```bash
cargo build --release --features led-indicator   # with-LED variant
cargo build --release --features battery-carrier-board  # no-LED variant
cargo build --release                             # default, unaffected
```

All three combinations were verified building against the crate's actual
pinned versions (`esp-idf-hal 0.45.2`, `esp-idf-sys 0.36.1`, ESP-IDF
`v5.2.3`) on the `riscv32imac-esp-espidf` target. Compiling against the
real toolchain caught two real bugs the original hand-written reference
had wrong:

- `AdcChannelConfig::calibration` is an enum (`Calibration::Curve` /
  `Line` / `None`) in this `esp-idf-hal` version, not the `bool` the
  reference assumed.
- `Ws2812Esp32Rmt` is feature-gated behind `ws2812-esp32-rmt-driver`'s own
  `smart-leds-trait` Cargo feature, which isn't on by default.

(The other previously-flagged uncertain spot — `Ws2812Esp32Rmt::new`'s
constructor signature — turned out to already match what the reference
assumed; only the feature flag was missing.) It adds three pieces:

- `servo` — replaces a bare PWM write with power-gated moves: energize VCC,
  settle 50 ms, command position, wait out travel, cut VCC. Drop the final
  `power_off()` call if the louver back-drives.
- `battery` — reads the 1:3 divider on GPIO1/A1, maps pack voltage to
  `Good`/`Ok`/`Low`/`Critical`. Thresholds stop at ~4.0 V (1.0 V/cell) to
  avoid cell reversal. NiMH's flat discharge curve makes this a coarse
  "roughly where am I" gauge, not a percentage fuel gauge — a coulomb
  counter would be the honest upgrade if more precision is needed later.
- `indicator` — drives the SK6812 as a small priority-ordered event
  dispatcher, since one LED ends up doing several jobs once more than one
  vent is installed:
  1. **Identify** — "find this vent," the primary use case. Blue blink,
     triggered from the app via the `/device/identity` handler (or the
     Matter Identify cluster). Always wins over the other events below —
     it's the one a person is actively looking at the hardware for.
  2. **Install** — pairing/commissioning feedback (`AwaitingCommission`,
     `Pairing`, `Commissioned`, `Error`). Only relevant pre-deployment, so
     it's allowed to be more liberal about on-time than the runtime events.
  3. **CommandResult** — a brief green/red blink confirming a command
     landed on *this* physical vent, useful for telling several vents
     apart while operating them from the app.
  4. **Battery** — the existing battery-state colour, shown after a move
     or an explicit query, not continuously.

  Nothing is ever left lit continuously regardless of event — that's the
  on-demand LED budget from §2. See the `Event`/`InstallState` enums in
  `indicator.rs` for the full state list.

The whole `indicator` module — and everything that calls into it — is
compiled in only when `led-indicator` is enabled, which is the no-LED
variant's actual situation, not just a suggestion: the feature flag
enforces it at the Cargo level rather than relying on someone remembering
to skip a file. `servo` and `battery` compile under just
`battery-carrier-board`, on either PCB variant.

What's still not done: nothing in `main.rs` calls into `carrier_board` yet
— no `Servo`/`PackSense`/`Indicator` is instantiated, no GPIO1/21/22 is
claimed from `Peripherals`. That's the remaining wiring work in #47:
replace the existing bare PWM write in the relevant call sites with
`carrier_board::servo::Servo::move_to()`, instantiate `PackSense` on
`adc1`/GPIO1, and hook `Indicator::show(Event::Identify)` into the
`/device/identity` handler and `Event::Install(...)` into the commissioning
flow. None of this has been flashed to real hardware — compiling is
verified, behavior on an actual XIAO is not.

## 9. Current state

What's done and machine-verified:

- **Circuit topology** — captured as a SKiDL script
  (`smart_vent_board.py`), with the LED indicator as a toggle
  (`SMART_VENT_LED=0`): 19 parts / 13 nets with LED, 16 parts / 10 nets
  without. Re-running either variant regenerates a byte-identical netlist
  (modulo random tags/timestamps), 0 errors.
- **Connectivity** — manually audited net-by-net: GND collects all returns,
  VBAT correctly feeds the 5V pin / P-FET source / divider / pullup, the
  gate chain is right, the sense divider lands on GPIO1.
- **KiCad netlist** (`smart_vent.net`) — importable into Pcbnew via
  File → Import → Netlist.
- **Floorplan** (`smart_vent_floorplan.svg`) — a placement plan, not yet
  applied to a real board file.
- **Placement script** (`place_smart_vent.py`) — a `pcbnew` scripting-console
  script that, run inside an actual KiCad PCB editor session after netlist
  import, positions all 19 footprints per the floorplan and draws the board
  outline + mounting holes. Written against the KiCad 7/8/9 API; not run
  against a live board in this pass (no `pcbnew` outside the KiCad GUI).

A placement-checked (but still unrouted) `.kicad_pcb` exists for both
variants, generated against KiCad 10.0.4 and machine-checked — see
`hardware/pcb/carrier-board-v1/kicad-project/`. That run confirmed two of
the three footprint pinouts flagged below against real stock-library parts
(SOT-23 pad geometry and the SK6812 PLCC4 pad order both match what the
netlist assumed).

**Placement is now clean on both variants** — this took two passes. The
floorplan's left/right/bottom *zoning* was always correct, but the exact
coordinates were sized around small SMD placeholders; once real stock
footprints went in (notably a THT slide switch for SW1 and a THT radial
cap for C2 — both substituted because no SMD match exists in KiCad's
stock libraries, see below — and both much bigger than what the floorplan
assumed), DRC found 3 shorts + 8 courtyard overlaps on the with-LED board
and 1 short + 5 overlaps on the no-LED board. An iterative solver
(`kicad-project/nudge_apart.py`) plus one manual follow-up — the servo
header J2 needed shifting both to clear the board's bottom edge (its last
pad, at the original anchor, landed entirely past the board outline) and
sideways to clear U1's placeholder footprint (a tall single-column header
shape that doesn't represent the real XIAO module at all) — resolved
every short, clearance violation, and courtyard overlap on both variants
down to zero. What's left in `kicad-project/drc_report*.json` is purely
cosmetic silkscreen-text overlap, not a routing or electrical concern.
Full before/after numbers and the placement rationale are in
`kicad-project/README.md`.

- **C2's exact footprint, `CP_Elec_6.3x5.4`, turned out to already be in
  KiCad's stock libraries** (under `Capacitor_SMD.pretty` — the first pass's
  search missed it). It's now the real footprint on both boards. Two
  placeholders remain: **no stock footprint exists for the Seeed XIAO
  module or the hobby-RC "SM-2P" battery connector**; both still need
  sourcing (or a confirmed substitute) before routing — see the placeholder
  table in `kicad-project/README.md`. (Applies to both variants; tracked in
  #45.)
- **The Gerber/drill export pipeline is confirmed working** against the
  unrouted boards — the JLCPCB-compatible layer set in §6 plots correctly.

What's still **not** done — placement is clean, but this is not fab-ready:

- No routing. Trace widths and the five layout rules (§5) are specified
  but not laid out on copper.
- No DRC pass against routed copper (the clean DRC reports are against
  unrouted placement only).
- The XIAO pad-order pinout still needs confirming once a real footprint is
  sourced (it's the one of the three "verify" callouts in §4 that couldn't
  be checked against a stock part) — and J2's exact position should be
  revisited once that footprint replaces U1's placeholder shape.

Follow-up work is tracked as GitHub issues (footprint sourcing in #45,
routing in #46, firmware integration of `power_indicator.rs` in #47).

Next concrete step: pick a variant (§2a), open the matching
`.kicad_pcb` in `hardware/pcb/carrier-board-v1/kicad-project/` in KiCad,
source/swap in the three missing footprints, clean up the cosmetic
silkscreen overlaps while you're in there, then route per the rules in §5
and DRC again before plotting Gerbers. The placement (left/right/bottom
zoning, no collisions) is ready to route against as-is.

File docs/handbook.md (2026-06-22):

# smart-vent Handbook

This is the conceptual reference for the smart-vent system. It explains what every
component does, how Matter and Thread fit together, what's happening inside the
ESP32-C6 firmware, what a single "close the vent" command actually traverses, and
why specific design choices were made. When you want a step-by-step recipe instead,
go to **[runbook.md](runbook.md)** — sections in this handbook cross-reference to
runbook procedures using "see runbook §N".

Read top-to-bottom on the first pass. After that, use the section headings as
landing pads.

---

## 1. Introduction and non-goals

The hardware unit is one HVAC vent. A small XIAO ESP32-C6 board sits inside the
vent box. A hobby SG90 servo on the board's GPIO2 pin physically rotates the vent
louver between **90° (fully closed)** and **180° (fully open)**. The board exposes
itself on a Thread mesh as a Matter **Window Covering** device. Home Assistant
(HA) running in Docker on a Raspberry Pi is the user-facing controller and
automation engine.

A single Raspberry Pi can host an arbitrary number of vents — every additional
vent is one more ESP32-C6 board on the same Thread mesh, joined to the same Matter
fabric. There is no cloud dependency, no Wi-Fi on the device, no HTTPS/MQTT, no
controller other than HA.

**Non-goals** (deliberate, not deferred):

- **No Wi-Fi on the vent.** ESP32-C6 has a Wi-Fi radio, but we leave it
  uncompiled (`CONFIG_ESP_WIFI_ENABLED=n`). Co-existing Wi-Fi and 802.15.4 on the
  same radio caused interrupt-watchdog panics on our firmware. See §10.1.
- **No Google Home / Alexa / Apple Home support.** The Pi's OTBR is a third-party
  Thread border router. Google Nest fabric (and similar) only routes Matter
  traffic through their own first-party border routers. HA, however, talks
  directly to our OTBR; that's why the controller stack is HA-only.
- **No legacy CoAP/Python hub.** Earlier iterations of this project had a
  Python hub and a custom HA integration talking to vents over CoAP. Those
  were removed; the supported control plane is **only** Matter-over-Thread.

> See runbook §1 for the "I already have this set up, just give me the next
> flashing command" quick path.

---

## 2. System architecture at a glance

The system is three layers (UI, gateway, device) plus two radios (BLE for
commissioning, 802.15.4 for normal operation). Everything inside the Pi runs as a
Docker container with `--network host` so the containers share the Pi's IPv6
stack and BLE adapter directly.

```
        ┌───────────────────────────── Raspberry Pi (Linux host) ─────────────────────────────┐
        │                                                                                       │
        │  ┌──────────────────┐    WebSocket    ┌────────────────────────┐                      │
        │  │ Home Assistant   │ ──────────────► │   matter-server        │                      │
        │  │   (port 8123)    │  ws://...:5580  │ (python-matter-server) │                      │
        │  │ ─────────────    │ ◄────────────── │   (port 5580)          │                      │
        │  │ Matter integ.    │  notifications  └────────┬─────┬─────────┘                      │
        │  │ (HA WebSocket    │                          │     │                                │
        │  │  client of MS)   │                          │     │ BLE pairing                    │
        │  └──────────────────┘                          │     ▼ (commissioning only)           │
        │           ▲                                    │   BlueZ ── (host adapter, hci0) ── ▒ │
        │           │ user clicks                        │                                      │
        │           │ Close/Open                         │ Matter operational                   │
        │           │                                    │ (UDP over IPv6, port 5540)           │
        │           │                                    ▼                                      │
        │           │                            ┌─────────────────────┐                        │
        │           │                            │  OTBR container     │                        │
        │           │                            │  (openthread/otbr)  │                        │
        │           │                            │  /dev/ttyUSB0       │                        │
        │           │                            └─────────┬───────────┘                        │
        │           │                                      │ 802.15.4 (Thread) via SLZB-07      │
        └───────────┼──────────────────────────────────────┼───────────────────────────────────┘
                    │                                      │  ▲
                    │ HA UI / API in browser                BLE 2.4 GHz from host hci0 ─ ─ ─ ─ ─ ┐
                    │ on phone/laptop                      │  │                                  │
                                                           ▼  │                                  │
                                                  ┌───────────┴─────────────┐                    │
                                                  │   XIAO ESP32-C6 (vent)  │  ◄─────────────────┘
                                                  │   Rust firmware         │
                                                  │   esp-matter (C++)      │
                                                  │   OpenThread stack      │
                                                  │                         │
                                                  │   GPIO2 (D2) ──► SG90   │
                                                  │                  servo  │
                                                  └─────────────────────────┘
```

Two transport protocols matter here, on two different radios.

- **BLE (Bluetooth Low Energy)** is used **only during commissioning**. The
  ESP32-C6 advertises a Matter commissioning service over BLE; matter-server,
  using BlueZ on the Pi, connects to it, runs the Matter PASE/CASE handshake,
  and pushes the Thread network credentials to the device. After commissioning
  the device stops BLE advertising and never uses BLE again unless factory-reset.
- **802.15.4 / Thread** is the steady-state transport for everything else. The
  SLZB-07 dongle gives the Pi an 802.15.4 radio; the OTBR container drives it,
  bridges between the Thread mesh and the Pi's wlan0 IPv6 network, and forwards
  Matter UDP packets in both directions.

There is no other connectivity between the Pi and the vent. The vent does not
join your Wi-Fi network. The Pi's Wi-Fi (or wired Ethernet) only connects the
Pi itself to your LAN so you can reach HA from your phone/laptop.

> See runbook §3 for how to bring the three Pi containers up; runbook §5–§6 for
> how to flash and commission a vent.

---

## 3. The Raspberry Pi hub

The Pi runs three Docker containers, all in `--network host` mode:

| Container | Image | Role | Port |
|---|---|---|---|
| `otbr` | `openthread/otbr:latest` | OpenThread Border Router. Drives the SLZB-07 radio, forms/joins the Thread mesh, bridges IPv6 between Thread and wlan0, runs the SRP server (see §5.6) | 80 (web GUI, optional) |
| `matter-server` | `ghcr.io/home-assistant-libs/python-matter-server:stable` | Matter controller. Holds the fabric credentials, NOC (Node Operational Certificate), ACLs. Talks Matter-over-IPv6 to commissioned devices. Exposes a WebSocket API for HA. Uses BlueZ for commissioning | 5580 (WS) |
| `homeassistant` | `ghcr.io/home-assistant/home-assistant:stable` | User-facing UI, automation engine, device registry. Its built-in **Matter (BETA)** integration is a WebSocket client of matter-server | 8123 (web) |

Using `--network host` is required for two reasons. First, OTBR has to assign and
route IPv6 prefixes on the host's actual interfaces; bridge networking would
isolate it. Second, Matter operational discovery uses mDNS over IPv6 link-local
multicast — that needs the host's real interface, not a docker0 bridge.

### 3.1 OTBR — OpenThread Border Router

OTBR has two jobs:

1. **Run the Thread network on the SLZB-07 radio.** The SLZB-07 is a "radio
   co-processor" (RCP) — a passive 802.15.4 transceiver with a serial protocol
   called Spinel. The dongle does the PHY/MAC; OTBR runs the entire Thread stack
   in software on the Pi and talks Spinel over `/dev/ttyUSB0` to the dongle.
   The dongle alone can't form a network.

2. **Bridge IPv6 between the Thread mesh and the Pi's wlan0.** A Thread mesh has
   its own IPv6 prefix (the **Mesh-Local ULA**, e.g. `fdf6:fb49:f2c1:1::/64`).
   For devices on wlan0 (matter-server, HA) to reach a Thread node, OTBR
   advertises an **Off-Mesh-Routable (OMR)** prefix into the Thread mesh, hands
   each mesh node an address from that prefix, and routes packets between
   mesh and wlan0. OMR addresses look like `fdbf:cc11:94a3:1e8c:…` on a typical
   setup. The "OMR" name is literally "addresses that are routable off the
   mesh" — i.e., reachable from the rest of the Pi.

OTBR exposes a CLI inside the container called **`ot-ctl`**. Useful commands:

- `docker exec otbr ot-ctl state` — `leader` / `router` / `child` / `disabled`.
  In a single-OTBR setup, the OTBR is always `leader`.
- `docker exec otbr ot-ctl child table` — list of end devices currently attached
  to this OTBR as their parent. Each row gives RLOC16 (short Thread address),
  age (seconds since last frame), RSSI, and Extended MAC (EUI-64). This is the
  canonical "is the vent on the mesh right now?" check. See §5.8.
- `docker exec otbr ot-ctl srp server host` and `ot-ctl srp server service` —
  what the OTBR's SRP server has stored for end devices that registered service
  records. See §5.6.
- `docker exec otbr ot-ctl dataset active -x` — dump the active Thread dataset
  (network key, channel, PAN ID, …) as a hex blob. The setup script backs this
  up to `~/.thread/dataset-backup.txt` for disaster recovery; if the OTBR
  container is wiped, restoring that blob recreates the same Thread network
  rather than forming a new one (which would orphan every commissioned vent).

OTBR needs two host-kernel modules loaded before it can route IPv6 properly:
`ip6table_filter` and `ip6_tables`. Without them, packets cross the mesh but
can't traverse OTBR's iptables rules into wlan0. Loading them is part of the
Pi setup (runbook §2.1).

### 3.2 matter-server — the Matter controller

`python-matter-server` is a small Python wrapper around the CHIP (Connected Home
over IP) SDK's controller library. It owns the **fabric** — the set of
commissioned devices that share trust roots — and the **NOC** (Node Operational
Certificate) that authenticates the controller to each device.

Once a device is commissioned, matter-server:

- Discovers it via mDNS (the device advertises `_matter._tcp.local`). See §5.5.
- Establishes a **CASE** (Certificate Authenticated Session Establishment)
  session — a TLS-like handshake over UDP that uses the fabric certificates.
- Subscribes to attribute reports so it sees state changes pushed by the device.
- Sends Invoke commands when HA or another client requests an action.

The WebSocket API on port 5580 lets HA (or any other client, like the Python
test scripts in `/tmp/` we used during commissioning sessions) read attributes,
invoke commands, and receive subscription pushes without speaking the Matter
wire protocol directly.

We deliberately run matter-server as a separate container rather than letting
HA Container's bundled matter-server handle it. The reasons are practical: it's
easier to debug (`docker logs matter-server`), easier to restart without
restarting HA, and the BLE permissions are scoped cleanly to one container.

matter-server gets the host BLE adapter via `-v /run/dbus:/run/dbus:ro` and the
`--bluetooth-adapter 0` flag (= `hci0`). That's the link to BlueZ; see §3.4.

### 3.3 Home Assistant — the user-facing controller

HA is what you actually use. The **Matter (BETA)** integration in HA does not
have its own Matter stack — it is a client of matter-server. You add it once,
pointing at `ws://localhost:5580/ws`, and from then on every commissioned
device shows up as one or more HA entities, with type derived from the device's
Matter cluster (a Window Covering becomes an HA `cover.*` entity).

For our vent, the entity exposes Open, Close, Stop, and a position slider.
"Open" sends Matter command `UpOrOpen`. "Close" sends `DownOrClose`. "Stop"
sends `StopMotion`. The slider sends `GoToLiftPercentage(value)`. Those
percentages are **percent100ths**: 0 = fully open, 10000 = fully closed. See
§4.4 for what the firmware does on the device side, and §7 for the full
command path.

> See runbook §3.3 for adding the Matter integration to HA. See runbook §7 for
> assigning the entity to a HA Area (room).

### 3.4 Host dependencies — BlueZ, kernel modules, USB layout

A few host-side details matter for reliability:

- **BlueZ** is the Linux Bluetooth daemon. It owns `hci0` (the Pi's onboard BT
  controller). matter-server speaks to BlueZ over D-Bus via the bind-mounted
  `/run/dbus` socket, and uses it to scan for and connect to commissioning
  advertisements. If BlueZ is unhappy — wedged connection, stale advertising
  cache — commissioning fails with `le-connection-abort-by-local` or silent
  timeouts. `sudo systemctl restart bluetooth` is the brute-force fix.
- **Kernel modules** `ip6table_filter` and `ip6_tables` need to be present;
  OTBR loads its iptables ruleset at startup and silently can't route without
  them. Persist via `/etc/modules-load.d/otbr.conf` (runbook §2.1).
- **USB layout** — both the XIAO and the SLZB-07 must plug into the Pi
  directly. A USB hub on the desk (we've identified a VIA Labs 2109:3431 +
  TI 0451:8442 chain that does this) will give the XIAO 5 V but no USB data,
  so it shows a power LED but no `/dev/ttyACM0`. Confirm with
  `lsusb -d 303a:` — the XIAO should appear as `Espressif USB JTAG/serial
  debug unit`. See runbook §5.1.

---

## 4. The ESP32-C6 vent controller

### 4.1 Hardware

The board is a **Seeed XIAO ESP32-C6** — a thumbnail-sized RISC-V module with
4 MB flash, 802.15.4 (for Thread) and BLE 5 (for commissioning) radios, and a
USB Type-C port wired to the chip's built-in USB Serial/JTAG.

Wiring:

| Function | Pin (XIAO label) | Pin (ESP32-C6 GPIO) | Wire | Notes |
|---|---|---|---|---|
| Servo signal | D2 | GPIO2 | yellow / orange | LEDC PWM @ 50 Hz, 14-bit resolution |
| Servo power | 5V | — | red | SG90 prefers ~5 V; XIAO's 5V pin is USB Vbus passthrough |
| Servo ground | GND | — | brown / black | shared with XIAO ground |
| USB | Type-C connector | — | USB cable | Power + serial + flashing path |

The XIAO's onboard USB Serial/JTAG enumerates as `/dev/ttyACM0` (vendor:product
`303a:1001`, "Espressif USB JTAG/serial debug unit"). espflash uses the same
port — no separate UART adapter needed.

This is the USB-powered wiring. For a battery-powered build (4-cell NiMH pack,
no USB tether), see [battery-carrier-board.md](battery-carrier-board.md) for
the carrier PCB design, BOM, and firmware integration notes — it's a separate
power path, not a replacement for the wiring above.

The USB-hub gotcha is one of the more annoying ones in this project: the chain
provides power but not data. Always plug the XIAO directly into a Pi USB port.
`lsusb -d 303a:` will return blank if it's going through the hub.

### 4.2 Firmware stack

The firmware is a Rust binary that links against the entire ESP-IDF v5.2.3 C
SDK plus Espressif's `esp-matter` SDK (which itself wraps the CHIP SDK in C++).
Conceptually:

```
   ┌────────────────────────────────────────┐
   │ vent-controller (Rust)                 │  src/*.rs — our code
   │   main.rs, matter.rs, servo.rs,        │
   │   state.rs, identity.rs, power.rs      │
   ├────────────────────────────────────────┤
   │ esp_matter_bridge (C++)                │  components/esp_matter_bridge/
   │   matter_bridge.cpp                    │  thin C++ shim — our code
   ├────────────────────────────────────────┤
   │ esp-matter (Espressif)                 │  cluster definitions, attribute
   │                                        │  store, endpoint factories
   ├────────────────────────────────────────┤
   │ CHIP SDK (Matter, C++)                 │  protocol-level Matter
   │                                        │  (PASE/CASE, IM, mDNS, BLE GATT)
   ├────────────────────────────────────────┤
   │ ESP-IDF v5.2.3                         │  FreeRTOS, OpenThread, NimBLE,
   │   FreeRTOS / OpenThread / NimBLE       │  NVS, LWIP, LEDC, drivers
   ├────────────────────────────────────────┤
   │ ESP32-C6 silicon                       │  RISC-V, 802.15.4, BLE radio
   └────────────────────────────────────────┘
```

The C++ shim exists because esp-matter is heavily C++ (templates, classes,
overloaded operators) and bridging it to Rust through bindgen would be brittle.
Instead, the shim exposes a small **C** API in
`components/esp_matter_bridge/include/matter_bridge.h`:

```c
int  matter_bridge_init(matter_position_cb_t pos_cb,
                        matter_identify_cb_t id_cb,
                        void *ctx);
int  matter_bridge_start(void);
void matter_bridge_update_position(uint16_t percent100ths);
void matter_bridge_update_operational_status(uint8_t status);
bool matter_bridge_is_commissioned(void);
int  matter_bridge_get_pairing_code(char *buf, size_t len);
int  matter_bridge_get_qr_payload(char *buf, size_t len);
void matter_bridge_factory_reset(void);
```

The Rust side (`src/matter.rs`) declares these `extern "C"` and wraps them in
safe Rust functions. Inbound callbacks (position change, identify) get a `*mut
c_void` user context that we leave null; instead, the callbacks reach into our
global app state (`with_app_state(|s| …)`).

### 4.3 Source module tour

```
firmware/vent-controller/src/
├── main.rs       Boot orchestrator: init logging, NVS, identity, WAL recovery,
│                 LEDC PWM, Matter, CoAP (legacy), then enter main loop.
├── matter.rs     Rust ↔ matter_bridge FFI; servo-angle ↔ percent100ths math;
│                 callbacks from CHIP into Rust.
├── thread.rs     `ThreadManager` — small query layer over OpenThread state
│                 (used for /device/health reports).
├── servo.rs      `ServoDriver` over `LedcDriver`. 50 Hz PWM, 500–2500 µs pulse
│                 for 0°–180°, step delay 15 ms.
├── state.rs      `VentStateMachine` (current/target angle + step) and
│                 `AppState` (singleton accessed via `with_app_state`).
├── identity.rs   `DeviceIdentity` — reads EUI-64 from eFuse, writes/reads
│                 NVS keys for room/floor/name/power_mode + the angle WAL.
├── power.rs      `PowerManager` / `PowerMode` (AlwaysOn vs Sed). Currently
│                 always-on; SED is a stub for future battery operation.
└── coap.rs       Legacy CoAP resources (`/vent/position`, `/vent/target`,
                  `/device/{identity,config,health}`). Still compiled in but
                  not on the supported control path; ignore in normal use.
```

**Boot sequence** (see `main.rs`):

1. `esp_idf_svc::sys::link_patches()` and `esp_idf_logger::init()` — set up logging.
2. `Peripherals::take()` and `EspDefaultNvsPartition::take()` — claim hardware.
3. `DeviceIdentity::new()` — read EUI-64 from eFuse, open NVS namespace `vent_cfg`.
4. `is_first_boot()` — read NVS key `init`; if missing, mark first boot.
5. **WAL (Write-Ahead Log) recovery.** Read NVS keys `wal` (commit flag),
   `angle` (last committed angle), `target` (pending target). If `wal == 0`,
   the previous move was interrupted by power loss; restore checkpoint angle
   and queue the pending target as the new target so the move replays. See
   §4.6 for the WAL design.
6. Configure LEDC timer (50 Hz, 14-bit), create `LedcDriver` on GPIO2, wrap in
   `ServoDriver`, call `set_angle(initial_angle)` to push the servo to its
   last-known-good position.
7. Build the `VentStateMachine` at the restored angle. If there's a pending
   WAL target, call `set_target(pending)` so the main loop will move there.
8. `matter::init()` — calls `matter_bridge_init()`. This creates the Matter
   node, the Window Covering endpoint at endpoint id 1, registers attribute-
   and identify-update callbacks. Notably it does **not** yet register the
   delegate (see §4.4).
9. `matter::start()` — calls `matter_bridge_start()`. This configures the
   OpenThread platform (the SLZB-07 on the device side is replaced by the
   C6's built-in 802.15.4 radio, `RADIO_MODE_NATIVE`), then calls
   `esp_matter::start()` which boots the CHIP server, mDNS responder, BLE
   GATT advertiser, and OpenThread stack. **After** `esp_matter::start()`
   returns, the delegate is registered.
10. `matter::log_pairing_info()` — log the manual pairing code and the QR
    payload to serial. You read these to commission the device (runbook §6.1).
11. Build the `AppState` aggregate and stash it in the global slot via
    `register_coap_resources(app_state)` (despite the name, that call is the
    one that publishes `AppState` to the callbacks; the CoAP side effects are
    incidental on the Matter path).
12. Enter the main loop: while `vent.is_moving()`, `step()` (advance current
    angle by 1° toward target), `servo.set_angle(current)`, sleep
    `STEP_DELAY_MS` (15 ms). When the move completes, `identity.commit(final_angle)`
    and `matter::report_position(final_angle)` / `report_operational_status(false)`.

### 4.4 The Window Covering cluster

Matter models a window covering (or vent louver, or roller shade) using the
**Window Covering** cluster, ID `0x0102`. The cluster has six relevant
attributes for our use:

| Attribute | ID | Type | Meaning |
|---|----|---|---|
| `Type` | 0x0000 | enum | What kind of covering — we use `Rollershade` |
| `CurrentPositionLiftPercent100ths` | 0x000E | u16 | Where the louver actually is, 0..10000 (0 = open) |
| `TargetPositionLiftPercent100ths` | 0x000B | u16 | Where we're moving to |
| `OperationalStatus` | 0x000A | bitmap | Bits for global/lift/tilt motion (opening/closing/stopped) |
| `ConfigStatus` | 0x0007 | bitmap | Reports cluster capabilities |
| `FeatureMap` | 0xFFFC | bitmap | Which Window Covering features are enabled |

And four commands:

| Command | ID | What it does |
|---|----|---|
| `UpOrOpen` | 0x00 | Move to fully open (Target = 0) |
| `DownOrClose` | 0x01 | Move to fully closed (Target = 10000) |
| `StopMotion` | 0x02 | Halt; cluster sets Target = Current |
| `GoToLiftPercentage` | 0x05 | Set Target to a specific percent100ths |

The Window Covering cluster is **heavily feature-gated**. Three things must be
true at the same time for incoming commands to actually fire callbacks into our
firmware:

1. **A `WindowCovering::Delegate` must be registered.** The cluster server, on
   receiving any of the four commands, validates the command and then calls
   the delegate's `HandleMovement` (for Up/Down/GoTo) or `HandleStopMotion`
   (for Stop). Without a delegate, CHIP logs `WindowCovering has no delegate
   set for endpoint:1` and silently drops Up/Down/GoTo. Only Stop has a
   default no-op handler.
2. **The delegate must be registered AFTER `esp_matter::start()`** — not before.
   The cluster server gets initialized inside `esp_matter::start()`; calling
   `WindowCovering::SetDefaultDelegate()` earlier doesn't stick. Our code does
   the registration as the last step of `matter_bridge_start()`.
3. **The `PositionAwareLift` feature must be added to the cluster's
   FeatureMap.** The cluster has an internal `HasFeature(endpoint, kPositionAwareLift)`
   guard around setting Target and calling HandleMovement. Without it, commands
   arrive at the cluster but skip the delegate path. Our code adds the feature
   in `matter_bridge_init` (right after creating the endpoint) by calling
   `cluster::window_covering::feature::lift::add()` and `position_aware_lift::add()`.

Missing any one of those three produces the same observable symptom: HA's
Close button does nothing, no logs on the device, no errors. This was one of
the harder bugs to find. See runbook §10.7 for the diagnostic.

### 4.5 percent100ths ↔ servo angle, and why u32

The conversion between Matter's percent100ths (0..10000, where 0 = fully open)
and our servo angle (90..180, where 180 = fully open) is in `src/matter.rs`:

```rust
pub fn angle_to_percent100ths(angle: u8) -> u16 {
    let clamped = angle.clamp(ANGLE_CLOSED, ANGLE_OPEN);
    let range = (ANGLE_OPEN - ANGLE_CLOSED) as u32; // 90
    let from_open = (ANGLE_OPEN - clamped) as u32;
    ((from_open * 10000) / range) as u16
}

pub fn percent100ths_to_angle(pct: u16) -> u8 {
    let clamped = pct.min(10000) as u32;
    let range = (ANGLE_OPEN - ANGLE_CLOSED) as u32; // 90
    let from_open = (clamped * range) / 10000;
    ANGLE_OPEN - from_open as u8
}
```

The **u32 promotion** matters. An older version computed `(clamped * range) /
10000` in u16. For `percent100ths_to_angle(10000)`: `10000 * 90 = 900000`,
which wraps the u16 to `900000 % 65536 = 48032`. Divided by 10000 that gives
4. `180 − 4 = 176`. So pressing Close in HA moved the servo to 176° (almost
fully open) instead of 90° (fully closed). The bug was silent because the
unit tests in the same file never ran — `vent-controller` is a binary-only
crate, so `cargo test` errors with "no library targets found" and exits zero.

Rule of thumb for any future arithmetic in this code path: when multiplying
two values that can each reach a few thousand, cast to u32 first.

### 4.6 NVS and persistent state

ESP32 has a **Non-Volatile Storage (NVS)** partition — a small key/value store
on the SPI flash, log-structured and wear-leveled by the IDF NVS driver. Our
firmware uses NVS for everything that has to survive a reboot:

| Owner | Namespace / partition | What's stored |
|---|---|---|
| Our firmware | `vent_cfg` namespace | `room`, `floor`, `name`, `pwr_mode`, `poll_ms`, plus the WAL keys |
| Our firmware (WAL) | `vent_cfg` namespace | `angle` (last committed servo angle, 1 byte), `target` (pending target, 1 byte), `wal` (commit flag, 1 byte) |
| OpenThread | `nvs` partition (default) | Active dataset (network key, channel, PAN ID, ext PAN ID, …), node info, MLE counters |
| CHIP/Matter | `nvs` partition (default) | Fabric table (fabric ID, root cert, NOC, ICA, IPK), ACLs, group keys, mDNS instance name, subscription resumption records |
| ESP-IDF | `phy_init` partition | RF calibration data |

The partition layout is fixed by `partitions.csv`:

```
nvs       data nvs     0x9000  0x6000  (24 KB)
phy_init  data phy     0xf000  0x1000  (4 KB)
factory   app  factory 0x10000 0x300000 (3 MB)
```

The 24 KB NVS is shared among Matter, OpenThread, and our `vent_cfg`. That's
plenty.

**"Wiping NVS"** specifically means erasing this 24 KB partition. After a wipe
the device looks like a fresh-from-the-factory unit: no fabric credentials, no
Thread dataset, no servo checkpoint. It will boot, fail `is_commissioned()`,
start BLE advertising the matter commissioning service, and wait to be
commissioned again. The runbook calls for an NVS wipe in specific scenarios:

- **After a firmware reflash that changes the Matter datamodel.** If you add a
  new cluster or change feature gating, subscription resumption records from
  the old build can cause CHIP to crash or behave oddly. Wiping NVS clears
  them.
- **When the device is "commissioned but unreachable" for a long time.** If
  HA has the device in its registry but matter-server times out every
  re-subscribe attempt and there are no mDNS records being advertised, NVS
  state can be stale; wipe + re-commission is faster than debugging.
- **When you don't have the matter-server fabric anymore.** If the Pi got
  wiped and matter-server lost its fabric, the device still thinks it's
  commissioned but to a fabric nobody knows. Wipe → re-commission.

To wipe NVS without re-flashing the app, with the device in download mode:
`espflash erase-partition nvs`. See runbook §5.4.

**Write-Ahead Log (WAL) on the angle.** SG90 servos don't report position, so
when power is cut mid-move we need to know where the louver is when we wake
up. The strategy is in `identity.rs`:

- Before the servo starts moving, the firmware calls `write_ahead(target)`:
  set NVS `target = target`, set `wal = 0` (uncommitted).
- The servo moves. No NVS writes during the move.
- When `current == target`, the firmware calls `commit(target)`: set
  `angle = target`, set `wal = 1`.

On boot, if `wal == 1` (or unset), the previous move committed cleanly:
restore `angle`. If `wal == 0`, the previous move was interrupted: restore
`angle` (the last known-good position before the move) and **replay**
`target` (so the move completes after power restoration). The NVS keys are
**overwritten in place** — total flash wear is 4 small writes per command
cycle, well within the partition's effective lifetime (we estimate ~16 years
at 100 commands/day).

> See runbook §5.4 for the wipe command, §9.3 for re-pair-after-wipe.

---

## 5. Matter and Thread, end-to-end

This section explains the protocol stack from the bottom up: the 802.15.4
radio, the Thread mesh, IPv6 routing, mDNS, SRP, Matter commissioning, Matter
operational. If you already know the protocols, skim — most subsections are
focused on the **smart-vent-specific** details (what addresses are involved,
what commands to use, what the failure modes look like).

### 5.1 What Matter is

**Matter** (formerly Project CHIP) is an application-layer protocol that runs
on top of IPv6. It is *transport-agnostic*: a Matter node can sit on Wi-Fi
(Matter-over-Wi-Fi), Ethernet, or Thread (Matter-over-Thread, what we use).
The semantics are the same; only the link layer differs.

A Matter device exposes:

- One or more **endpoints** (logical components). Endpoint 0 is always the
  "root endpoint" hosting administrative clusters (Basic Information, Network
  Commissioning, Operational Credentials, etc.). Other endpoints are
  app-specific. Our vent has endpoint 1 = Window Covering.
- A set of **clusters** per endpoint. A cluster is a typed bundle of
  **attributes** (state), **commands** (actions), and **events** (signals
  from the device to the controller). Window Covering is one cluster; an
  endpoint can host many.
- A **fabric** membership. Every commissioned controller-device pair belongs
  to one or more fabrics. Each fabric has a root certificate, and each node
  on the fabric is issued a **NOC (Node Operational Certificate)** signed by
  that root.

Matter wire traffic during operation is UDP on port **5540**, encrypted under
session keys derived from the NOC and the controller's certificate via
**CASE (Certificate Authenticated Session Establishment)**. CASE looks much
like TLS 1.3 — it's an X.509-based, mutually-authenticated key exchange that
produces a per-session symmetric key.

The protocol layer above CASE is the **Interaction Model (IM)**, which
defines `ReadRequest`, `WriteRequest`, `InvokeRequest`, `SubscribeRequest`,
and their responses. When HA pushes the Open button, that's an
`InvokeRequest` carrying a Window Covering `UpOrOpen` command, traveling over
a CASE session, riding on a UDP packet, hopping through the Thread mesh.

### 5.2 What Thread is

**Thread** is a low-power IPv6 mesh network on IEEE 802.15.4 (the same PHY
that Zigbee uses, but with very different upper layers). A Thread network has:

- **Routers** (and one **Leader** elected from the routers). They route
  packets through the mesh and accept new attachments.
- **End devices** — children of a router. They don't route. There are three
  flavors: **REED** (router-eligible end device, can promote to router),
  **MED** (minimal end device, RX-on-when-idle, doesn't sleep), and
  **SED** (sleepy end device, polls parent, sleeps between polls). Our vent
  is configured as MTD = "minimal Thread device" which presents as MED.

Every Thread node has at least three IPv6 addresses:

- A **link-local address** (`fe80::…`) used for MLE (mesh link establishment)
  and one-hop neighbor traffic.
- A **mesh-local ULA** in the Thread mesh-local prefix (e.g.,
  `fdf6:fb49:f2c1:1::/64`) used for routing inside the mesh.
- One or more **OMR (Off-Mesh-Routable)** addresses, derived from the OMR
  prefix the OTBR delegates. These are how off-mesh hosts (matter-server,
  HA) reach the device.

The OTBR is a Thread router (specifically a **Border Router**). Off-mesh
traffic gets to the device via:
`matter-server (on wlan0) → wlan0 (Pi) → OTBR netfilter rules →
wpan0 (OTBR's Thread NIC) → Thread mesh → vent`.

The vent's **EUI-64** (extended MAC) is its permanent identifier on Thread.
On ESP32-C6 it's burned into eFuse at the factory. Our firmware reads it
with `esp_efuse_mac_get_default()` (see `identity.rs:read_eui64`) and uses
it both for logging and as the IEEE 802.15.4 extended address.

### 5.3 What a Thread Border Router actually does

A Thread Border Router (TBR) sits with one foot in the Thread mesh and one
foot on a "backbone" network (Wi-Fi or Ethernet). It does five things:

1. **Joins the Thread mesh as a router.** OTBR participates in the routing
   protocol like any other router.
2. **Advertises an OMR prefix** into the mesh. Devices on the mesh learn
   they can reach the rest of the world via this prefix. They configure an
   OMR address using SLAAC and announce it.
3. **Routes IPv6 packets between the mesh and the backbone.** Forward
   path: backbone → OTBR → Thread mesh. Reverse path: mesh → OTBR →
   backbone. The OTBR's netfilter ruleset handles NAT66/forwarding details.
4. **Reflects mDNS between the two sides.** The Thread mesh has its own
   multicast group; mDNS announcements from a Thread node have to be
   re-emitted on wlan0 to reach controllers there. OTBR does this via its
   SRP server (see §5.6) plus its mDNS proxy.
5. **Runs the SRP server.** End devices push their service records to OTBR
   over the mesh; OTBR re-advertises them via Avahi on the backbone.

When `ot-ctl state` reports `leader`, OTBR is also the network leader, which
adds the responsibility of generating the routing locator (RLOC16) and
network-wide configuration. In a single-OTBR setup the leader role is
unremarkable.

### 5.4 The Thread Dataset and credential push

A Thread network is identified by its **Active Operational Dataset**: a
binary structure containing the **network key** (the symmetric key for all
802.15.4 MAC-layer encryption), **channel** (e.g. 15), **PAN ID** (16-bit
network ID), **extended PAN ID** (64-bit), **mesh-local prefix**, **security
policy**, and a timestamp. Any device with this dataset can join the network.

Two relevant facts:

- The dataset is the secret. If you compromise it, you can sniff all Thread
  traffic in that network.
- A device that doesn't have the dataset cannot communicate on the mesh at
  all (not even to MLE-discover its parent).

**Credential push** during commissioning is the moment when matter-server
takes the active dataset from OTBR (via `ot-ctl dataset active -x`) and
sends it to the device over the BLE PASE session. The device stores the
dataset in NVS (under the OpenThread partition keys), attaches to the mesh,
and from then on it's a regular Thread end device. We never send the dataset
over Wi-Fi or any unsecured link — it always travels inside the encrypted
PASE channel.

If you wipe the device's NVS, the dataset is gone with it. The device will
boot, find no dataset, advertise BLE for re-commissioning.

### 5.5 mDNS and `avahi-browse`

**mDNS** (Multicast DNS) is the discovery protocol Matter uses on the local
link. Devices advertise records under `_matter._tcp.local` for operational
(commissioned) services and `_matterc._udp.local` for commissioning
(pre-fabric) services. The records contain:

- The Matter operational name (a 16-byte hex tag: 8-byte Compressed Fabric
  ID + 8-byte Node ID, hyphenated), e.g. `9C7219E1805D505D-000000000000000E`.
- An A/AAAA record giving the device's IPv6 address.
- TXT records with capabilities, retry intervals, etc.

When matter-server wants to talk to a commissioned device, it doesn't have
the device's IP cached — it does `_matter._tcp.local PTR` lookups, finds
the record, resolves the AAAA, and opens a CASE session. Subscriptions
re-resolve when they renew (every 30–60 s).

You can inspect the mDNS records the Pi sees with `avahi-browse`:

```
avahi-browse -art _matter._tcp _matterc._udp
```

This lists every record currently advertised on any interface. If the vent
has registered its `_matter._tcp` record (via SRP, see next section), it'll
appear here with its IPv6 address. If it doesn't, mDNS-based discovery
won't work — that's the "device looks alive but matter-server can't reach
it" failure mode.

### 5.6 SRP server and service registration

A Thread device cannot directly emit mDNS multicast on the Wi-Fi/Ethernet
side — it's on the Thread mesh, the multicast scope is different. The
**Service Registration Protocol (SRP)** solves this. SRP is, conceptually,
"DNS UPDATE over UDP, sent from a Thread end device to the OTBR." The OTBR
runs an SRP server; end devices use the OpenThread SRP client.

Workflow:

1. The CHIP mDNS responder on the device decides it wants to advertise
   `_matter._tcp._fabric=01_node=0E.local`.
2. The OpenThread SRP client packages that record as an SRP update message.
3. The message is sent over the mesh to the SRP server (running inside
   OTBR; configured via the active dataset).
4. OTBR's SRP server accepts the update, stores the record under the
   device's host name, and re-emits it as a regular mDNS record on wlan0
   via Avahi.
5. matter-server, listening on wlan0, sees the record and learns the
   device's address.

You can list what the SRP server currently holds with:

```
docker exec otbr ot-ctl srp server host
docker exec otbr ot-ctl srp server service
```

`host` shows the registered host names + IPv6 addresses (one host per
device). `service` shows the service instances under those hosts. Empty
output means no end device has currently registered — either the device
isn't on the mesh, or its CHIP mDNS responder isn't trying, or the SRP
update is failing.

**SRP registration drops** are a known instability with our firmware. The
CHIP mDNS responder advertises at startup, then re-advertises on a
schedule. If the responder hits a transient OpenThread packet-queue-full
condition during the re-advertise (which it has, during heavy MLE traffic),
the SRP record can expire on the server without being renewed. Symptom:
`ot-ctl srp server host` goes from "shows the device" to "empty" while the
device is still on the mesh (you can see its child entry in
`ot-ctl child table`). matter-server then loses operational reachability
even though the device is fine. Power-cycling the device usually restores
the SRP record within a minute (because boot triggers a fresh advertise).

### 5.7 OMR IPv6

The **Off-Mesh-Routable (OMR)** address is the address an off-mesh host
uses to reach a Thread device. OTBR advertises an OMR prefix into the mesh
(typically a /64 like `fdbf:cc11:94a3:1e8c::/64`). Thread devices auto-
configure an OMR address from this prefix using SLAAC: prefix + 64 bits
derived from the device's MAC.

Three useful operations:

- **Find a device's OMR addresses**: in the device's serial log on boot,
  it logs every IPv6 address it gets; alternatively, use matter-server's
  `ping_node` API which returns all known addresses for a node id and
  whether each currently pings (we used this several times during
  debugging — see the python scripts under `/tmp/` from previous sessions
  if you need a template).
- **Ping an OMR address from the Pi**: `ping6 -c 3 <omr-address>`. This
  proves IPv6 reachability without involving Matter / CASE / mDNS at all.
- **Direct-IP commissioning**: matter-server can be handed an explicit
  IPv6 address to commission against, bypassing mDNS entirely. Useful
  when SRP isn't working (see §6.5).

### 5.8 The OTBR child table

`docker exec otbr ot-ctl child table` is the canonical "is the device on
Thread right now?" check. Sample output:

```
| ID  | RLOC16 | Timeout | Age | LQ In | C_VN |R|D|N|Ver|CSL|QMsgCnt|Suprvsn| Extended MAC     |
+-----+--------+---------+-----+-------+------+-+-+-+---+---+-------+-------+------------------+
|   1 | 0x3801 |     240 |  34 |     3 |  199 |1|0|0|  4| 0 |     0 |   129 | 366c8ec439fa22b1 |
```

- **ID** — short local id used by OTBR for this child.
- **RLOC16** — 16-bit routing locator; the child's short Thread address.
- **Timeout** — seconds the parent waits before evicting; default 240.
- **Age** — seconds since the parent last heard a frame from this child.
  Low (<30 s for MED) means the device is currently active.
- **Extended MAC** — the child's 8-byte EUI-64. This is the **device-side
  EUI**, equal to what `esp_efuse_mac_get_default()` returns. It's how you
  correlate the child entry with a specific vent.

If the device is on Thread you'll see a row. If not — the row is missing
or "Age" climbs toward 240 — the device is either powered off, out of
range, or has lost its Thread credentials.

### 5.9 "Device on Thread" — the operational checklist

"Is the vent on Thread?" decomposes into four checks, top to bottom:

1. **Is it powered and running?** Serial log emits new lines.
2. **Has it joined the mesh?** `ot-ctl child table` shows a row whose
   Extended MAC matches the vent's EUI-64, with low Age.
3. **Has it advertised SRP?** `ot-ctl srp server host` lists a host whose
   name contains the device's CHIP fabric/node tag, and `srp server
   service` lists a `_matter._tcp` instance for that host.
4. **Is matter-server seeing it via mDNS?** `avahi-browse -art _matter._tcp`
   shows the same instance. matter-server logs show
   `Re-Subscription succeeded` or equivalent.

If 1–3 are green but 4 is red, the issue is on the Pi side (Avahi, OTBR's
mDNS proxy, matter-server). If 3 is red but 2 is green, the device's CHIP
mDNS / SRP layer is stuck — power-cycle the device. If 2 is red but 1 is
green, the device hasn't joined — check the Thread credentials (was it
commissioned to a different network?). If 1 is red, plug it in.

> Runbook §6.3 has these as copy-paste verification commands.

---

## 6. Commissioning deep dive

Commissioning is the multi-step handshake that turns an out-of-the-box
ESP32-C6 into a member of your Matter fabric on your Thread mesh. It's
also where most of the time-consuming failures happen. This section
explains what's happening so the symptom-driven recipes in the runbook
make sense.

### 6.1 BLE commissioning

A fresh device (no NVS commissioning state) wakes up, fails
`matter_bridge_is_commissioned()`, and starts the NimBLE GATT server
advertising a Matter commissioning service. The advertisement contains:

- Vendor ID and Product ID (we use `0xFFF1` / `0x8001` — Matter test
  vendor/product, fine for a private hub).
- **Discriminator** — a 12-bit number used to disambiguate multiple
  devices advertising at once. Our firmware derives it from the lower
  12 bits of `EUI-64[6..8]`, so it's unique per board without manual
  config.
- **Passcode**-derived data (a SPAKE2+ verifier) used in PASE.

matter-server, via BlueZ, scans for advertisements, recognizes the
Matter service UUID, and connects. It then runs **PASE (Passcode
Authenticated Session Establishment)** with the device using the
manual pairing code or QR payload you provided. The pairing code
contains the discriminator (so matter-server knows which advertisement
to talk to) and the SPAKE2+ passcode.

After PASE succeeds, both sides share a session key. Over that key
matter-server:

1. Sends the **Operational Credentials** cluster commands to issue
   the device its NOC (Node Operational Certificate) and the fabric
   root cert.
2. Sends the **Network Commissioning** cluster commands carrying the
   **Thread dataset** (network key, channel, PAN ID, etc., gathered
   from OTBR via `ot-ctl dataset active -x`).
3. Tells the device to **CommissioningComplete**, which closes PASE.

The device now stores its NOC + fabric cert + thread dataset in NVS,
brings up OpenThread with the dataset, attaches to the mesh, and
starts the CHIP mDNS responder.

Symptoms of BLE failures and what they mean:

- **`le-connection-abort-by-local` in matter-server logs.** BlueZ-side
  hiccup. Restart `bluetooth.service`, retry.
- **No advertisements seen at all.** Either the device's BLE adv
  window has expired (next subsection), or the host's BlueZ adapter is
  in scan-blocked state. Power-cycle the device first; if that doesn't
  help, restart `bluetooth.service`.
- **Advertisements seen, connect fails or hangs.** Could be an old
  cached pairing in BlueZ's bookkeeping. `bluetoothctl > remove
  <addr>` for the device's BLE address, retry.

### 6.2 Fast-adv vs slow-adv windows

The CHIP SDK doesn't BLE-advertise forever — that would be a battery
drain on real battery devices, and on USB-powered devices it pollutes
the air for everyone. The pattern is:

- **Fast advertising window**: roughly **15 minutes** after the device
  boots into commissioning mode (i.e., uncommissioned, fresh boot or
  factory-reset). During this window the BLE adv interval is short
  (~30 ms typical), and matter-server picks the device up promptly.
- **Slow advertising**: after the fast window, the device keeps
  advertising at a much longer interval (~1 s) for some hours.
  Discoverable but slower to find.
- **Off**: eventually, no advertising. The device is sitting there
  waiting for a manual prod.

This is why **the practical commissioning workflow is: flash → boot →
commission within ~10 minutes**. If you flash a board, then go make
coffee, then forget about it for an hour, then come back and try to
commission, you might still succeed (slow-adv), or you might find
matter-server timing out and need to **power-cycle the device first**
to restart the fast-adv window.

This is also why the runbook §5 emphasizes "have HA's Matter UI ready
on your phone before you replug the device."

### 6.3 Thread credential push, in detail

Inside the PASE channel, matter-server sends a sequence of cluster
commands. The relevant ones for getting the device onto Thread:

1. **NetworkCommissioning::ScanNetworks** (optional) — ask the device
   to scan for networks. For Thread, this returns the channels it's
   listening on, but it's not required if matter-server already knows
   which dataset to push.
2. **NetworkCommissioning::AddOrUpdateThreadNetwork** — payload is the
   active dataset (the same hex blob you'd get from `ot-ctl dataset
   active -x`). The device stores it in NVS but doesn't activate yet.
3. **NetworkCommissioning::ConnectNetwork** — the device activates
   the dataset, calls `otThreadSetEnabled(true)`, and reports back
   over PASE whether it joined.
4. **Once the device confirms attached**, matter-server proceeds to
   the operational handoff: PASE closes, device starts CHIP mDNS,
   matter-server discovers via mDNS and opens CASE.

If you see in the serial log:

```
chip[NWPROV]: Setting Thread provision
chip[DL]: OpenThread started: OK
chip[DL]: Setting OpenThread device type to MINIMAL END DEVICE
```

…you're past step 2.

### 6.4 mDNS-based operational discovery

After PASE closes, the device is a regular commissioned node. matter-server
needs to find it again via mDNS to open the operational CASE session.

Two ways this can work:

- **Via SRP + Avahi (the normal path).** Device → SRP client → OTBR's SRP
  server → Avahi → wlan0 mDNS → matter-server. This is the "happy path"
  and is what runbook §6.3 verifies.
- **Via the device's own mDNS responder on the mesh-local prefix**, which
  OTBR's mDNS proxy then bridges to wlan0. This is a fallback when SRP
  fails for whatever reason; it's less reliable.

When mDNS discovery succeeds, matter-server logs:

```
<Node:14> Discovered on mDNS
<Node:14> Setting-up node...
<Node:14> Establishing CASE session...
<Node:14> Re-Subscription succeeded
```

### 6.5 Direct IP commissioning (bypassing mDNS)

When SRP isn't registering and mDNS-based discovery times out, you can
bypass mDNS entirely by handing matter-server an explicit IPv6 address —
typically the device's OMR address.

There are two flavors:

- **Initial commissioning over IP.** Less common; only used if the
  device is already on the Thread mesh from a previous commissioning
  attempt but the BLE-based path keeps failing. matter-server's
  `commission_with_code` command accepts an `ip_addr` parameter; pass
  the OMR address along with the setup code.
- **Operational reachability after losing mDNS.** Once the device is
  commissioned, matter-server caches the address from the last
  successful discovery. If you query a node attribute and the cached
  address is stale, matter-server returns
  `AddressResolve_DefaultImpl.cpp:124: Timeout`. There isn't a clean
  way to inject a new address via the public API — you have to either
  wait for the device to re-advertise (power-cycle it), or wipe
  matter-server's storage and re-commission.

Direct-IP commissioning is the escape valve; SRP-driven mDNS is the
normal flow. If you find yourself reaching for direct IP often, the
device's SRP responder needs fixing, not a workaround.

### 6.6 Post-flash behavior

What happens immediately after `espflash` finishes depends on what was
in NVS when you flashed:

- **NVS preserved (the default, no `erase-partition` flag).** The
  device boots with whatever state it had: if it was commissioned to a
  fabric, it's still commissioned; if it had a checkpoint angle, that
  angle is restored; if there was a pending WAL move, it replays.
  No BLE advertising unless the device fails to attach to its old
  Thread network. This is the **fast path** for iterating on firmware
  without losing commissioning state.
- **NVS wiped (`espflash erase-partition nvs`).** First boot, no fabric,
  no dataset. BLE fast-adv starts. The device is ready for a fresh
  commission via HA. Use this when you've changed Matter cluster
  configuration, when the device is stuck in some bad state, or when
  you want to commission to a different fabric.

> Runbook §5.4 documents when to wipe; §6 covers re-commissioning after
> a wipe.

---
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

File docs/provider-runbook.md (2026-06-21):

# Provider runbook

You're the **provider**: you assemble kits and ship them to clients.
A kit is one Pi + one SLZB-07 dongle + N vents (XIAO ESP32-C6 + SG90
servo + louver) + printed paperwork.

This runbook walks through every step from blank hardware to a
boxed-and-labeled kit ready to ship. The client does only one thing:
plug it in and commission their vents through the Home Assistant
app.

Everything here uses the `smart-vent-provision` CLI. If you want to
understand **why** any step is the way it is, jump to
[`handbook.md`](handbook.md). If you want the developer flow (build
firmware from source, hand-flash, hand-commission), see
[`runbook.md`](runbook.md).

---

## 1. One-time setup (laptop)

You'll need this set up once on your laptop. After that every kit
is just §3.

### 1.1 Tools

```
python3 (>= 3.11)
pip
sudo                          # the image subcommand writes to /dev/sdX
xz, dd                        # ship with any Debian/Ubuntu/macOS install
espflash (>= 3.0)             # cargo install espflash --version '^3'
SD-card reader                # USB or built-in
```

The `flash` and `capture` subcommands talk to XIAO ESP32-C6 boards
over USB. Plug each XIAO **directly** into your laptop — not via a
hub. The SMLIGHT SLZB-07 dongle goes in the client's Pi, not your
laptop.

### 1.2 Install the CLI

```bash
pip install --user \
  https://github.com/EtaCassiopeia/smart-vent/releases/download/provision-v0.1.0/smart_vent_provision-0.1.0-py3-none-any.whl

# Verify:
smart-vent-provision --version
smart-vent-provision --help
```

Subsequent releases publish at the same URL pattern. The CLI
auto-resolves to the latest `firmware-v*` and `hub-v*` releases when
you don't pin a tag.

---

## 2. What goes into a kit

| Item | Source | Notes |
|---|---|---|
| Raspberry Pi (4 or 5) | Off-the-shelf | Any model with USB + WiFi or Ethernet |
| SD card (≥ 16 GB) | Off-the-shelf | Class 10 / A1 recommended |
| SMLIGHT SLZB-07 USB dongle | <https://smlight.tech> | Thread radio for OTBR |
| N × XIAO ESP32-C6 boards | <https://www.seeedstudio.com> | One per vent |
| N × SG90 servos | Off-the-shelf | One per vent |
| N × vent louver assemblies | Per-house (3D-print or buy) | The mechanical part |
| Printed sticker sheet | `provision labels` (Avery 5160) | One QR sticker per vent |
| Printed quick-start card | `provision kit-card` | Goes in the box |

---
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

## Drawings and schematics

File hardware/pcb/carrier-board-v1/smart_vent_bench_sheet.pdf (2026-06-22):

# smart-vent carrier — bench sheet

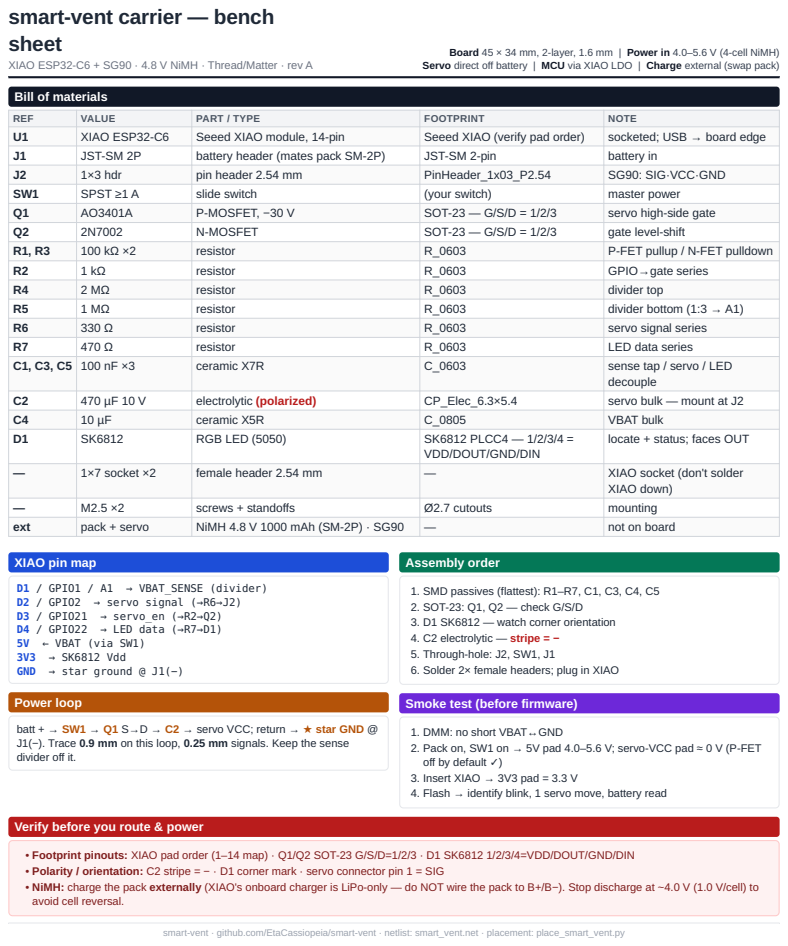
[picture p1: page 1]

Board 45 × 34 mm, 2-layer, 1.6 mm | Power in 4.0–5.6 V (4-cell NiMH)
Servo direct off battery | MCU via XIAO LDO | Charge external (swap pack)

XIAO ESP32-C6 + SG90 · 4.8 V NiMH · Thread/Matter · rev A

REF | VALUE | PART / TYPE | FOOTPRINT | NOTE
U1 | XIAO ESP32-C6 | Seeed XIAO module, 14-pin | Seeed XIAO (verify pad order) | socketed; USB → board edge
J1 | JST-SM 2P | battery header (mates pack SM-2P) | JST-SM 2-pin | battery in
J2 | 1×3 hdr | pin header 2.54 mm | PinHeader_1x03_P2.54 | SG90: SIG·VCC·GND
SW1 | SPST ≥1 A | slide switch | (your switch) | master power
Q1 | AO3401A | P-MOSFET, −30 V | SOT-23 — G/S/D = 1/2/3 | servo high-side gate
Q2 | 2N7002 | N-MOSFET | SOT-23 — G/S/D = 1/2/3 | gate level-shift
R1, R3 | 100 kΩ ×2 | resistor | R_0603 | P-FET pullup / N-FET pulldown
R2 | 1 kΩ | resistor | R_0603 | GPIO→gate series
R4 | 2 MΩ | resistor | R_0603 | divider top
R5 | 1 MΩ | resistor | R_0603 | divider bottom (1:3 → A1)
R6 | 330 Ω | resistor | R_0603 | servo signal series
R7 | 470 Ω | resistor | R_0603 | LED data series
C1, C3, C5 | 100 nF ×3 | ceramic X7R | C_0603 | sense tap / servo / LED decouple

C2 | 470 µF 10 V | electrolytic (polarized) | CP_Elec_6.3×5.4 | servo bulk — mount at J2
C4 | 10 µF | ceramic X5R | C_0805 | VBAT bulk
D1 | SK6812 | RGB LED (5050) | SK6812 PLCC4 — 1/2/3/4 = VDD/DOUT/GND/DIN | locate + status; faces OUT

— | 1×7 socket ×2 | female header 2.54 mm | — | XIAO socket (don't solder XIAO down)

— | M2.5 ×2 | screws + standoffs | Ø2.7 cutouts | mounting
ext | pack + servo | NiMH 4.8 V 1000 mAh (SM-2P) · SG90 | — | not on board

SMD passives (flattest): R1–R7, C1, C3, C4, C5
SOT-23: Q1, Q2 — check G/S/D
D1 SK6812 — watch corner orientation
C2 electrolytic — stripe = −
Through-hole: J2, SW1, J1
Solder 2× female headers; plug in XIAO

Smoke test (before firmware)

batt + → SW1 → Q1 S→D → C2 → servo VCC; return → ★ star GND @
J1(−). Trace 0.9 mm on this loop, 0.25 mm signals. Keep the sense
divider off it.

DMM: no short VBAT↔GND
Pack on, SW1 on → 5V pad 4.0–5.6 V; servo-VCC pad ≈ 0 V (P-FET
off by default ✓)
Insert XIAO → 3V3 pad = 3.3 V
Flash → identify blink, 1 servo move, battery read

Verify before you route & power

Footprint pinouts: XIAO pad order (1–14 map) · Q1/Q2 SOT-23 G/S/D=1/2/3 · D1 SK6812 1/2/3/4=VDD/DOUT/GND/DIN
Polarity / orientation: C2 stripe = − · D1 corner mark · servo connector pin 1 = SIG
NiMH: charge the pack externally (XIAO's onboard charger is LiPo-only — do NOT wire the pack to B+/B−). Stop discharge at ~4.0 V (1.0 V/cell) to
avoid cell reversal.

smart-vent · github.com/EtaCassiopeia/smart-vent · netlist: smart_vent.net · placement: place_smart_vent.py

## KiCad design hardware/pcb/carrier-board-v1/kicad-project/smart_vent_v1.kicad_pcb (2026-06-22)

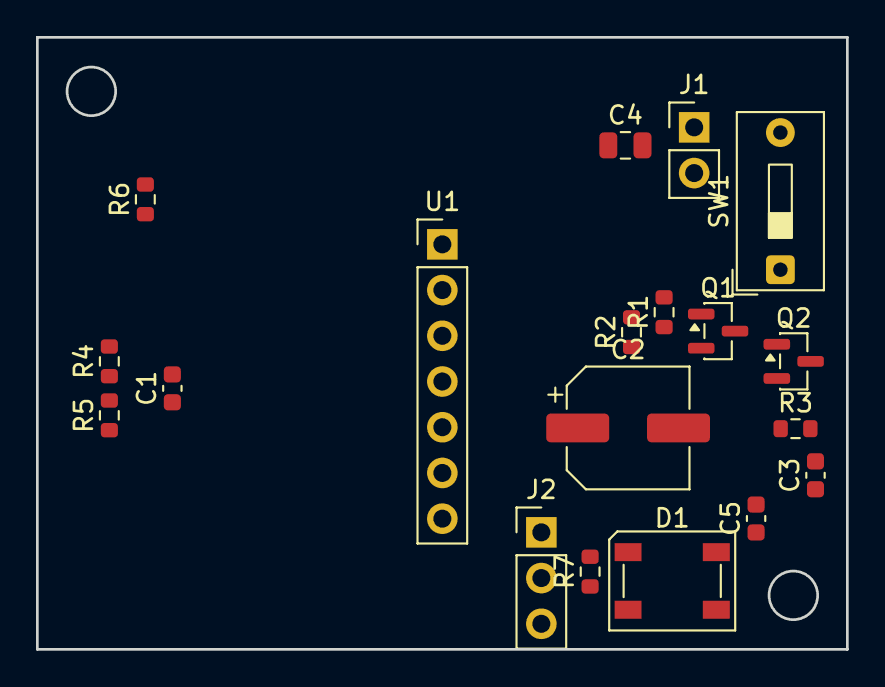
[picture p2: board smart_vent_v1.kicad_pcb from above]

Board: 2 copper layers, 45.0 x 34.0 mm, 19 parts (0 on the bottom side), 10 nets, no tracks yet.

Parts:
C1, C3, C5: C_0603_1608Metric
C2: CP_Elec_6.3x5.4
C4: C_0805_2012Metric
D1: LED_SK6812_PLCC4_5.0x5.0mm_P3.2mm
J1: PinHeader_1x02_P2.54mm_Vertical
J2: PinHeader_1x03_P2.54mm_Vertical
Q1, Q2: SOT-23
R1, R2, R3, R4, R5, R6, R7: R_0603_1608Metric
SW1: SW_DIP_SPSTx01_Slide_9.78x4.72mm_W7.62mm_P2.54mm
U1: PinHeader_1x07_P2.54mm_Vertical

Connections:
GND: C1.2, C2.2, C3.2, C4.2, C5.2, D1.3, J1.2, J2.3, Q2.2, R5.2
LED_DIN: D1.4, R7.2
NFET_GATE: Q2.1, R2.2, R3.1
PFET_GATE: Q1.1, Q2.3, R1.2
SERVO_SIG: J2.1, R6.2
SERVO_VCC: C2.1, C3.1, J2.2, Q1.3
V3V3: C5.1, D1.1
VBAT: C4.1, Q1.2, R1.1, R4.1, SW1.2
VBAT_RAW: J1.1, SW1.1
VBAT_SENSE: C1.1, R4.2, R5.1

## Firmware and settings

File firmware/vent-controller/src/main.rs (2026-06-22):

#[cfg(feature = "battery-carrier-board")]
mod carrier_board;
#[allow(dead_code)]
mod identity;
#[allow(dead_code)]
mod matter;
#[allow(dead_code)]
mod power;
#[allow(dead_code)]
mod servo;
#[allow(dead_code)]
mod state;
#[allow(dead_code)]
mod thread;

use identity::DeviceIdentity;
use power::{PowerManager, PowerMode};
use servo::ServoDriver;
use state::{AppState, VentStateMachine};
use thread::ThreadManager;
use vent_protocol::{PowerSource, ANGLE_CLOSED};

use esp_idf_hal::ledc::{config::TimerConfig, LedcDriver, LedcTimerDriver, Resolution};
use esp_idf_hal::peripherals::Peripherals;
use esp_idf_hal::prelude::*;
use esp_idf_svc::nvs::EspDefaultNvsPartition;
use log::{error, info, warn};
use std::thread::sleep;
use std::time::{Duration, Instant};

fn main() {
    // Initialize ESP-IDF logging and system
    esp_idf_svc::sys::link_patches();
    esp_idf_logger::init().expect("Failed to init logger");

    info!("Vent Controller v{}", env!("CARGO_PKG_VERSION"));
    info!("Wakeup cause: {}", PowerManager::wakeup_cause_str());

    // Initialize peripherals
    let peripherals = Peripherals::take().expect("Failed to take peripherals");
    let nvs_partition = EspDefaultNvsPartition::take().expect("Failed to init NVS");

    // Initialize device identity
    let mut device_id = DeviceIdentity::new(nvs_partition).expect("Failed to init identity");
    info!("EUI-64: {}", device_id.eui64());

    // Check first boot
    match device_id.is_first_boot() {
        Ok(true) => {
            info!("First boot detected — initializing defaults");
            if let Err(e) = device_id.mark_initialized() {
                warn!("Failed to mark initialized: {:?}", e);
            }
        }
        Ok(false) => info!("Device previously initialized"),
        Err(e) => warn!("Could not check boot status: {:?}", e),
    }

    // WAL recovery — check if previous move was committed
    let committed = device_id.is_committed().unwrap_or(true);
    let (initial_angle, pending_target) = if committed {
        // Normal boot: restore last checkpoint
        let angle = device_id
            .checkpoint_angle()
            .ok()
            .flatten()
            .unwrap_or(ANGLE_CLOSED);
        info!("Restoring checkpoint: {}°", angle);
        (angle, None)
    } else {
        // Uncommitted move: intent was written-ahead but never committed.
        // Restore the last checkpoint first (known-good position), then
        // replay the pending target to complete the interrupted move.
        let checkpoint = device_id
            .checkpoint_angle()
            .ok()
            .flatten()
            .unwrap_or(ANGLE_CLOSED);
        let pending = device_id.get_pending().ok().flatten();
        warn!(
            "WAL recovery: uncommitted move detected. Checkpoint: {}°, pending: {:?}",
            checkpoint, pending
        );
        (checkpoint, pending)
    };

    // Initialize servo via LEDC PWM
    let timer_config = TimerConfig::default()
        .frequency(50.Hz().into())
        .resolution(Resolution::Bits14);
    let timer = LedcTimerDriver::new(
        peripherals.ledc.timer0,
        &timer_config,
    )
    .expect("Failed to init LEDC timer");

    let ledc_driver = LedcDriver::new(
        peripherals.ledc.channel0,
        timer,
        peripherals.pins.gpio2, // SG90 signal pin (XIAO ESP32C6 D2)
    )
    .expect("Failed to init LEDC channel");

    let mut servo = ServoDriver::new(ledc_driver).expect("Failed to init servo");
    if let Err(e) = servo.set_angle(initial_angle) {
        error!("Failed to set initial servo angle: {:?}", e);
    }

    // Initialize state machine at last known position
    let mut vent_state = VentStateMachine::new(initial_angle);

    // If a pending target exists from an interrupted move, replay it
    if let Some(target) = pending_target {
        info!("Replaying interrupted command: target {}°", target);
        vent_state.set_target(target);
    }

    // Determine power mode from NVS (default: always-on)
    let power_mode = match device_id.get_power_mode() {
        Ok(Some(mode_str)) => {
            let poll_ms = device_id.get_poll_period().ok().flatten().unwrap_or(5000);
            let mode = PowerMode::from_nvs_str(&mode_str, poll_ms);
            info!("Power mode from NVS: {}", mode.as_str());
            mode
        }
        _ => {
            info!("Power mode: always_on (default)");
            PowerMode::AlwaysOn
        }
    };
    let power_mgr = PowerManager::new(power_mode);

    // Thread networking is managed by Matter SDK — only create a query handle
    let thread_mgr = ThreadManager::new_matter_managed();

    // Configure SED if battery-powered
    if let Err(e) = power_mgr.configure_sed() {
        error!("Failed to configure SED mode: {:?}", e);
    }

    // Initialize Matter (creates node + Window Covering endpoint).
    // Matter manages the OpenThread stack and its mainloop internally.
    matter::init();
    matter::start();
    matter::log_pairing_info();

    // Build and publish the shared AppState. The main loop and Matter
    // handlers both reach into it via state::with_app_state.
    let app_state = AppState {
        vent: vent_state,
        identity: device_id,
        thread: thread_mgr,
        start_time: Instant::now(),
        power_source: match power_mode {
            PowerMode::AlwaysOn => PowerSource::Usb,
            PowerMode::Sed { .. } => PowerSource::Battery,
        },
        poll_period_ms: power_mode.poll_period_ms(),
        identify_mode: false,
        identify_restore_angle: None,
    };
    state::init_app_state(app_state);

    info!("Vent controller running. Waiting for Matter commands...");

    // Main loop: process servo steps and Thread events
    loop {
        let is_moving = state::with_app_state(|s| s.vent.is_moving()).unwrap_or(false);

        if is_moving {
            state::with_app_state(|s| s.vent.step());

            let current_angle = state::with_app_state(|s| s.vent.current_angle()).unwrap_or(ANGLE_CLOSED);
            if let Err(e) = servo.set_angle(current_angle) {
                error!("Servo step failed: {:?}", e);
            }
            sleep(Duration::from_millis(servo::STEP_DELAY_MS as u64));

            // Commit when movement completes: checkpoint angle + set WAL flag
            let still_moving = state::with_app_state(|s| s.vent.is_moving()).unwrap_or(false);
            if !still_moving {
                state::with_app_state(|s| {
                    let final_angle = s.vent.current_angle();

                    // During identify, wiggle back and forth instead of committing
                    if s.identify_mode {
                        if let Some(restore) = s.identify_restore_angle {
                            // Toggle between restore angle and wiggle offset
                            let next = if final_angle == restore {
                                restore.saturating_add(10).min(vent_protocol::ANGLE_OPEN)
                            } else {
                                restore
                            };
                            s.vent.set_target(next);
                        }
                        return;
                    }

                    if let Err(e) = s.identity.commit(final_angle) {
                        error!("WAL commit failed: {:?}", e);
                    }
                    info!(
                        "Vent reached target: {}° ({}) — committed",
                        final_angle,
                        s.vent.state().as_str()
                    );

                    // Report final position to Matter fabric
                    matter::report_position(final_angle);
                    matter::report_operational_status(false);
                });
            }
        } else {
            // Idle — sleep briefly to yield CPU
            sleep(Duration::from_millis(100));
        }
    }
}

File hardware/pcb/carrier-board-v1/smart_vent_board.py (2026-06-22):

#!/usr/bin/env python3
"""
smart-vent carrier board — circuit described as code (SKiDL).

The status LED (D1/R7/C5, GPIO22) is OPTIONAL. It's the locate/status
indicator described in docs/battery-carrier-board.md; skipping it removes
one idle SK6812 load from the 3V3 rail for builds that don't need it.
Generates two netlists, one per variant:

    python3 smart_vent_board.py            -> smart_vent.net          (with LED)
    SMART_VENT_LED=0 python3 smart_vent_board.py  -> smart_vent_no_led.net (without)

Parts are defined inline (tool=SKIDL) so this runs with NO KiCad symbol
libraries installed. Footprints are assigned as strings; swap any of them
for the exact part/footprint you order. The XIAO pin NUMBERS below follow the
common community 14-pin XIAO footprint (1..7 = D0..D6, 8..11 = D7..D10,
12 = 3V3, 13 = GND, 14 = 5V). >>> Verify against the footprint you actually
drop in (the official Seeed XIAO footprint) before routing. <<<
"""

import os
from skidl import Part, Pin, Net, TEMPLATE, SKIDL, generate_netlist

INCLUDE_LED = os.environ.get("SMART_VENT_LED", "1") != "0"

P = Pin.types.PASSIVE  # treat everything as passive -> keeps ERC quiet


# ---------------------------------------------------------------- templates
def passive(prefix, npins=2):
    pins = [Pin(num=str(i + 1), name=str(i + 1), func=P) for i in range(npins)]
    return Part(tool=SKIDL, name=prefix, ref_prefix=prefix, dest=TEMPLATE, pins=pins)


R = passive("R")
C = passive("C")
SW = passive("SW")  # SPST master switch (2 terminals)
J2 = passive("J", 2)  # battery connector (2-pin)
J3 = passive("J", 3)  # servo connector (3-pin)

MOSFET = Part(
    tool=SKIDL, name="MOSFET", ref_prefix="Q", dest=TEMPLATE,
    pins=[Pin(num="1", name="G", func=P),
          Pin(num="2", name="S", func=P),
          Pin(num="3", name="D", func=P)],
)

if INCLUDE_LED:
    LED = Part(
        tool=SKIDL, name="SK6812", ref_prefix="D", dest=TEMPLATE,
        pins=[Pin(num="1", name="VDD", func=P),
              Pin(num="2", name="DOUT", func=P),
              Pin(num="3", name="GND", func=P),
              Pin(num="4", name="DIN", func=P)],
    )

# XIAO ESP32-C6 module, 14 pads (see header note for numbering)
XIAO = Part(
    tool=SKIDL, name="XIAO_ESP32C6", ref_prefix="U", dest=TEMPLATE,
    pins=[
        Pin(num="1", name="D0_GPIO0", func=P),   # unused (strapping-adjacent; left NC)
        Pin(num="2", name="D1_GPIO1", func=P),   # battery sense (A1)
        Pin(num="3", name="D2_GPIO2", func=P),   # servo signal
        Pin(num="4", name="D3_GPIO21", func=P),  # servo_en
        Pin(num="5", name="D4_GPIO22", func=P),  # LED data (only wired if INCLUDE_LED)
        Pin(num="6", name="D5_GPIO23", func=P),  # NC
        Pin(num="7", name="D6_GPIO16", func=P),  # NC
        Pin(num="8", name="D7_GPIO17", func=P),  # NC
        Pin(num="9", name="D8_GPIO19", func=P),  # NC
        Pin(num="10", name="D9_GPIO20", func=P), # NC
        Pin(num="11", name="D10_GPIO18", func=P),# NC
        Pin(num="12", name="3V3", func=P),
        Pin(num="13", name="GND", func=P),
        Pin(num="14", name="5V", func=P),        # board power in (from battery via switch)
    ],
)


# ---------------------------------------------------------------- instances
def fp(part, footprint):
    part.footprint = footprint
    return part

U1 = fp(XIAO(value="XIAO ESP32-C6"),
        "Seeed:XIAO-ESP32C6")  # replace w/ the exact Seeed XIAO footprint

JBAT = fp(J2(value="SM-2P battery"),
          "Connector_JST:JST_SH_BM02B-SRSS-TB_1x02-1MP_P1.00mm_Vertical")
SW1 = fp(SW(value="SPST master"),
         "Button_Switch_SMD:SW_SPST_PTS810")  # placeholder; use a slide switch >=1A
JSRV = fp(J3(value="SG90 servo"),
          "Connector_PinHeader_2.54mm:PinHeader_1x03_P2.54mm_Vertical")

Q1 = fp(MOSFET(value="AO3401A (P)"), "Package_TO_SOT_SMD:SOT-23")   # servo high-side
Q2 = fp(MOSFET(value="2N7002 (N)"), "Package_TO_SOT_SMD:SOT-23")    # gate level-shift

R1 = fp(R(value="100k"), "Resistor_SMD:R_0603_1608Metric")   # P-FET gate pullup -> VBAT
R2 = fp(R(value="1k"),   "Resistor_SMD:R_0603_1608Metric")   # GPIO -> N-FET gate series
R3 = fp(R(value="100k"), "Resistor_SMD:R_0603_1608Metric")   # N-FET gate pulldown -> GND
R4 = fp(R(value="2M"),   "Resistor_SMD:R_0603_1608Metric")   # divider top  (VBAT -> SENSE)
R5 = fp(R(value="1M"),   "Resistor_SMD:R_0603_1608Metric")   # divider bottom (SENSE -> GND)
R6 = fp(R(value="330R"), "Resistor_SMD:R_0603_1608Metric")   # servo signal series

C1 = fp(C(value="100nF"), "Capacitor_SMD:C_0603_1608Metric")          # sense tap
C2 = fp(C(value="470uF"), "Capacitor_SMD:CP_Elec_6.3x5.4")            # servo bulk (polarized)
C3 = fp(C(value="100nF"), "Capacitor_SMD:C_0603_1608Metric")          # servo decouple
C4 = fp(C(value="10uF"),  "Capacitor_SMD:C_0805_2012Metric")         # VBAT bulk
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

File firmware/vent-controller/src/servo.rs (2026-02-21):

use esp_idf_hal::ledc::LedcDriver;
use esp_idf_sys::EspError;

/// SG90 servo PWM parameters.
const PWM_FREQ_HZ: u32 = 50;
const MIN_PULSE_US: u32 = 500;   // 0° position
const MAX_PULSE_US: u32 = 2500;  // 180° position
const PERIOD_US: u32 = 20_000;   // 50 Hz = 20ms

/// Step delay in milliseconds for gradual movement.
pub const STEP_DELAY_MS: u32 = 15;

/// Servo driver wrapping LEDC PWM.
pub struct ServoDriver<'d> {
    ledc: LedcDriver<'d>,
    max_duty: u32,
}

impl<'d> ServoDriver<'d> {
    /// Create a new servo driver on the given LEDC channel and GPIO pin.
    pub fn new(
        ledc: LedcDriver<'d>,
    ) -> Result<Self, EspError> {
        let max_duty = ledc.get_max_duty();
        Ok(Self { ledc, max_duty })
    }

    /// Set servo angle (0–180 degrees).
    pub fn set_angle(&mut self, angle: u8) -> Result<(), EspError> {
        let duty = self.angle_to_duty(angle);
        self.ledc.set_duty(duty)?;
        Ok(())
    }

    /// Convert angle (0–180) to LEDC duty cycle value.
    fn angle_to_duty(&self, angle: u8) -> u32 {
        let angle = angle.min(180) as u32;
        let pulse_us = MIN_PULSE_US + (angle * (MAX_PULSE_US - MIN_PULSE_US)) / 180;
        (pulse_us * self.max_duty) / PERIOD_US
    }

    /// Disable PWM output (stop holding servo position).
    pub fn disable(&mut self) -> Result<(), EspError> {
        self.ledc.set_duty(0)?;
        Ok(())
    }
}

#[cfg(test)]
mod tests {
    // Servo hardware tests require ESP32 target.
    // Use the state machine tests in state.rs for host-side testing.
    // Integration tests run on-device via `cargo run`.
}

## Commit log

2026-02-19 Initial implementation of smart vent control system
    Rust ESP32-C6 firmware (servo, Thread, CoAP, deep sleep), Python hub
    service (device registry, group manager, OTBR discovery, CLI), device
    simulator for hardware-free testing, and Home Assistant custom component
    exposing vents as cover entities. Includes RFC, protocol spec, setup
    guides, and full test suites (5 Rust + 34 Python tests passing).
2026-02-19 Add comprehensive architecture doc with full glossary
    Covers system overview, physical/network/application layers, data flow
    diagrams, device lifecycle, power architecture, security model, testing
    strategy, and a glossary of every component, protocol, and technical
    term used in the project (~60 entries).
2026-02-19 Convert architecture diagrams to Mermaid where they improve readability
    Replaced 5 ASCII diagrams with Mermaid equivalents:
    - Thread Mesh Topology (3.2) → graph with color-coded node roles
    - Request/Response Flow (4.3) → sequenceDiagram
    - HA Dashboard data flow (6.1) → sequenceDiagram
    - Device Discovery flow (6.2) → sequenceDiagram
    - Device Lifecycle (7) → stateDiagram-v2
    Kept ASCII for spatial/layout diagrams (system overview, hardware
    pinouts, protocol stack, CoAP tree, CBOR encoding, power timelines,
    security boundary, test pyramid) where Mermaid would reduce clarity.
2026-02-19 Fix Mermaid diagrams for GitHub rendering
    - Remove special unicode chars that break GitHub Mermaid renderer
    - Remove curly braces and parentheses from message labels
    - Simplify stateDiagram to flat structure (GitHub has limited
    support for nested states and notes)
    - Move device lifecycle details into a companion table
2026-02-19 Replace ASCII diagrams with D2-rendered SVGs
    Add docs/diagrams/ with D2 source files and rendered SVGs for:
    - system-overview: full system layout (hub + mesh + devices)
    - architecture-simple: compact version for README and RFC
    - vent-node: ESP32-C6 hardware block diagram
    - hub-hardware: Raspberry Pi 4B layout
    - protocol-stack: network layers from physical to application
    - security-model: trust boundary and threat model
    - test-architecture: test pyramid and simulator
    - state-machine: vent state transitions
    - wiring: ESP32-C6 to SG90 servo connections
    Updated architecture.md, rfc.md, wiring.md, and README.md to
    reference SVGs instead of ASCII art. D2 sources are kept alongside
    SVGs for versio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
2026-02-19 Switch D2 diagrams to dark color palette
    Updated all D2 source files to use dark fills with bright accent
    strokes instead of light fills. Consistent palette across all
    diagrams: dark blue for hub, dark green for services, dark purple
    for mesh/devices, dark red for security boundaries, dark orange
    for warnings and highlights.
2026-02-19 Add write-ahead recovery for interrupted servo moves
    If power is lost mid-move, the device now recovers correctly on
    reboot instead of snapping to a stale position.
    Protocol (event-sourcing inspired):
    1. Command received: save target + clear finalized flag in NVS
    2. Servo moves toward target
    3. Movement completes: save final angle + set finalized flag
    On boot, if finalized flag is unset:
    - Drive servo to last known good position first
    - Replay the pending target command to completion
    - Finalize
    NVS keys: "angle" (last finalized), "target" (write-ahead),
    "fin" (0=pending, 1=complete).
    [identity.rs, main.rs]
2026-02-19 Rename recovery mechanism to standard WAL terminology
    Renamed firmware APIs to match write-ahead log pattern:
    save_pending_target() → write_ahead()
    get_pending_target() → get_pending()
    finalize_move() → commit()
    is_finalized() → is_committed()
    get_saved_angle() → checkpoint_angle()
    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
2026-02-19 Clarify write-ahead checkpoint is fixed-size, not append-only
    The recovery mechanism uses 3 overwritten NVS keys (3 bytes total,
    constant) rather than an append-only log. Updated code comments and
    architecture doc section 8.4 to make this distinction clear:
    - Renamed section to "Write-Ahead Checkpoint Recovery"
    - Added naming note explaining difference from traditional WAL
    - Added NVS key table showing constant 1-byte-per-key storage
    - Documented the 4-writes-per-cycle protocol explicitly
    - Added flash wear analysis (600K commands, ~16 years at 100/day)
    - Updated glossary entry from "WAL" to "Write-Ahead Checkpoint"
    [identity.rs]
2026-02-19 Fix RSSI reporting: use otThreadGetParentAverageRssi instead of RLOC16 (#9)
    get_rssi() was casting mRloc16 (a network address) to i8, returning
    garbage. Now calls otThreadGetParentAverageRssi() for the real value.
    Also wires ThreadManager into AppState so the health endpoint returns
    live RSSI instead of a hardcoded -50.
    Fixes #3
    [main.rs]
2026-02-19 Log errors instead of silently discarding with .ok() (#10)
    Replace four .ok() calls in main.rs with explicit error logging:
    - mark_initialized(): warn on NVS write failure
    - servo.set_angle() on boot: error if initial position fails
    - configure_sed(): error if SED config fails (battery drain risk)
    - servo.set_angle() in loop: error on servo step failure
    Fixes #4
    [main.rs]
2026-02-19 Read power mode from NVS instead of hardcoding AlwaysOn (#11)
    Add get_power_mode/set_power_mode and get_poll_period/set_poll_period
    NVS accessors to DeviceIdentity. On boot, read power mode from NVS
    and fall back to AlwaysOn if unset, so battery-powered devices can
    enter SED mode without reflashing.
    Fixes #5
    [identity.rs, main.rs]
2026-02-19 Add /device/health polling to HA coordinator (#12)
    The coordinator now fetches /device/health on each poll cycle,
    exposing RSSI, power source, free heap, and battery voltage.
    Cover entity extra_state_attributes include the health fields.
    Fixes #6
2026-02-19 Fix is_opening/is_closing to detect vent direction (#13)
    Both properties returned state=="moving" making them indistinguishable.
    Now the coordinator tracks the target angle from set_vent_position and
    includes it in poll data. The cover entity compares current angle vs
    target to determine if the vent is opening (target > current) or
    closing (target < current).
    Fixes #7
2026-02-19 Update docs to reflect fixes #3-#8 (#15)
    - architecture.md: Add pwr_mode/poll_ms to NVS table, update
    identity.rs/thread.rs/coap.rs/coordinator.py/cover.py descriptions
    - communication-protocol.md: Clarify RSSI source (otThreadGetParentAverageRssi)
    - rfc.md: Add NVS power mode keys to device identity section,
    fix incorrect /device/config reference for poll period,
    update HA integration section with health polling and direction detection
2026-02-21 Fix firmware build errors and unused imports
    - Disambiguate DeviceIdentity name collision in coap.rs by qualifying
    with vent_protocol:: to use the CBOR type instead of the NVS manager
    - Fix borrow checker error in identity.rs get_string by saving val.len()
    before reborrowing buf
    - Remove spurious i8 cast in thread.rs network name copy
    - Remove unused imports (CoapMethod, CoapResponse, SpeedMode)
    [identity.rs, main.rs]
2026-02-21 Fix OT binding names, remove otCoapStart, clean up warnings
    - Use otError_OT_ERROR_NONE instead of OT_ERROR_NONE to match
    esp-idf-sys generated binding names
    - Replace missing otDatasetCreateNewNetwork with manual dataset
    component flags
    - Remove otCoapStart call (CoAP API not in ESP-IDF OT bindings)
    - Remove unused imports in servo.rs and state.rs
    - Suppress dead_code warnings on WIP modules
    - Suppress unreachable_code on enter_deep_sleep
    [main.rs, servo.rs]
2026-02-21 Enable CoAP API for OpenThread MTD builds
    The OpenThread CoAP API (otCoapStart, etc.) is only enabled by default
    for FTD builds. Since our device runs as MTD, add a custom ESP-IDF
    component that sets OPENTHREAD_CONFIG_COAP_API_ENABLE=1 globally.
    The esp-idf-sys bindings header does not include openthread/coap.h, so
    otCoapStart is declared via extern "C" in coap.rs. The symbol is
    verified present in libopenthread.a.
2026-02-21 Fix CoAP addressing and drop unnecessary aiocoap extras
    The %25 zone ID hack for encoding ports in IPv6 addresses never
    worked — aiocoap treats it as a zone ID, not a port, so requests
    went to default port 5683 instead of the simulator's port.
    Replace with standard [host]:port URI format. CoapClient._build_uri
    detects bracketed addresses and constructs proper CoAP URIs. Plain
    IPv6 addresses use the default CoAP port.
    Also drop aiocoap[all] extra from hub and simulator — the base
    package provides UDP transport; [all] pulls in lakers-python and
    DTLSSocket which require Rust/C compilation and aren't needed.
2026-02-21 Add Zed IDE settings and update setup guide
    Add .zed/settings.json with rust-analyzer config targeting ESP32-C6.
    Update setup guide to document both Zed and VS Code configuration.
2026-02-21 Clarify Quick Start workflow in README
    Explain what the simulator does, lead with running tests as the
    primary verification step, and note that vent-hub discover requires
    a real Thread Border Router.
2026-02-22 Add SMLIGHT SLZB-07 as supported Thread RCP dongle
    Update setup guide, OTBR script, architecture docs, and RFC to
    support the SLZB-07 alongside the existing nRF52840 dongle. The
    setup script now auto-detects dongle type by USB vendor ID and
    sets the correct serial device and baud rate.
2026-02-22 Add ip6tables kernel module setup for OTBR on Raspberry Pi
    OTBR requires ip6table_filter and ip6_tables modules which are not
    loaded by default on Raspberry Pi OS. Added modprobe step to the
    setup script (auto-detected) and documented it in the setup guide.
2026-02-22 Add security note on generating unique Thread credentials
    Default OTBR datasets may use demo credentials. Added guide for
    generating a unique network key, PSKc, and custom network name
    for production deployments.
2026-02-22 Switch servo pin from GPIO6 to D2/GPIO2 for XIAO ESP32C6
    GPIO6 is on the MTCK bottom pad of the XIAO board, not accessible
    from the standard header pins. GPIO2 (D2) is on the header, supports
    PWM, and has no boot strapping conflicts. Updated wiring doc with
    full XIAO ESP32C6 pinout reference and ASCII wiring diagram.
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2026-02-22 Add XIAO ESP32C6 pin list image and detailed pin table
    Added the pin mapping diagram from Seeed Studio wiki and expanded
    the pin table with default functions and alternate functions for
    all header pins.
2026-02-22 Use large partition table and size-optimized release builds
    The debug build (1.56MB) exceeds the default 1MB app partition.
    Switched to CONFIG_PARTITION_TABLE_SINGLE_APP_LARGE (1.5MB) and
    added opt-level="s" for release builds. Release binary is 822KB
    (53% of partition). Flashed successfully to XIAO ESP32C6.
2026-02-22 Update flash guide for XIAO ESP32C6 and release builds
    Replaced generic ESP32-C6 references with XIAO-specific device
    paths and notes. Added --release requirement (debug build exceeds
    partition size), explicit --port flag, and D2/GPIO2 servo pin in
    troubleshooting.
2026-02-22 Add network key to Thread config and rewrite commissioning guide
    The firmware was missing the Network Key in its Thread dataset,
    so the device could never join the OTBR's network. Added network
    key field to ThreadConfig with default development credentials.
    Rewrote commissioning.md to use ot-ctl instead of REST API and
    explain how to match credentials between OTBR and firmware.
    Updated setup-rpi.md with matching ot-ctl commands.
2026-02-22 Match Thread credentials to OTBR active dataset
    Updated firmware ThreadConfig to match the OTBR's actual dataset:
    network name "OpenThreadDemo", channel 15, PAN ID 0x1234. Network
    key was already matching. Updated docs to reflect these values.
2026-02-22 Start OpenThread event loop in dedicated thread
    The OpenThread mainloop (esp_openthread_launch_mainloop) was never
    called, so the radio never processed frames and the device could
    not join the Thread network. Spawned a dedicated thread with 8KB
    stack to run the blocking mainloop alongside the servo control loop.
2026-02-22 Fix firmware boot crashes: LEDC timer, eventfd, and port config
    Three issues prevented the firmware from booting on ESP32-C6:
    1. LEDC PWM timer: 50Hz with default 8-bit duty resolution is not
    achievable on ESP32-C6. Set explicit 14-bit resolution.
    2. OpenThread eventfd: The task queue requires VFS eventfd support.
    Added esp_vfs_eventfd_register(), esp_event_loop_create_default(),
    and esp_netif_init() before esp_openthread_init(). Added
    CONFIG_VFS_SUPPORT_SELECT and CONFIG_ESP_EVENTFD to sdkconfig.
    3. OpenThread port_config: Default::default() zeros queue sizes,
    causing pvPortMalloc(0) → NULL → FreeRTOS assert. Set
    storage_partition_name="nvs", netif_queue_size=10, ta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
    [main.rs]
2026-02-22 Update docs to reflect actual boot output and Thread joining
    - flash-firmware.md: Update expected binary size (922KB) and serial
    output to match actual boot sequence including OpenThread mainloop
    and Thread role transition
    - commissioning.md: Update expected serial output to use default dev
    credentials (channel 15, OpenThreadDemo), add Role detached->child
    as the indicator of a successful join, add mainloop troubleshooting
2026-02-22 Add hub install note to commissioning discovery step
    Clarify that discovery runs on the Raspberry Pi hub and link to
    setup-dev-env.md for full Python environment setup.
2026-02-22 Switch discovery from OTBR REST API to ot-ctl
    The OTBR REST API returns 404 with --network host. Replace aiohttp
    calls with subprocess exec of `docker exec otbr ot-ctl` commands
    (state + childip6) and remove the aiohttp dependency.
    [cli.py]
2026-02-22 Wire CoAP resource handlers to OpenThread CoAP server
    Register a default CoAP handler via otCoapSetDefaultHandler that
    extracts URI path and method from incoming requests, delegates to
    route_request(), and sends back CBOR responses. Moves AppState into
    a Mutex<Option<AppState>> static so both the OT callback and main
    loop can access it safely.
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2026-02-22 HA integration: read devices from hub DB, fix CBOR array handling
    - Coordinator reads device addresses from hub's SQLite database
    instead of static config entry list
    - Add db_path config option (default /config/devices.db)
    - Fix all CBOR response parsing to handle arrays (minicbor format)
    - Fix set_target to send CBOR array payload
    - Auto-add new device entities on coordinator updates
    - setup_ha.sh mounts hub DB into HA container
    - setup_otbr.sh auto-detects backbone interface
    - Commissioning docs: prerequisites, troubleshooting, HA setup
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2026-05-22 Add Matter over Thread support (#30)
    [partitions.csv]
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2026-06-20 Grant workflow contents:write for release publishing (#35)
    Adds a top-level permissions block so softprops/action-gh-release can create GitHub Releases. Tag firmware-v0.1.0 was deleted before this fix and will be re-cut after merge.
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2026-06-21 PR B: Pi runtime — compose + install + systemd + first-boot wizard (#38)
    Adds everything that lands on /opt/smart-vent/ on a client Pi:
    pi/docker-compose.yaml OTBR + matter-server + Home Assistant,
    host network, BACKBONE_INTERFACE from
    .env, pinned image tags.
    pi/install.sh Idempotent installer. Curl-piped from
    GitHub at the latest hub-v* tag, or
    from a local checkout via SMART_VENT_SRC.
    --skip-wizard for wired/pre-seeded
    installs, --dry-run for safe preview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
2026-06-21 Install ip6_tables + ip6table_filter for OTBR routing (#40)
    OTBR needs the IPv6 netfilter kernel modules loaded to route
    Thread <-> backbone (wlan0/eth0). PR B (#38) and PR C (#39) both
    shipped without them; the original runbook §2.1 had the operator
    modprobe them by hand. Without these modules OTBR comes up, vents
    join Thread, SRP registers — but matter-server can't resolve their
    addresses and HA shows every vent Unavailable forever.
    Adds pi/config/modules-load.d/otbr.conf as the source of truth.
    Both install paths drop it to /etc/modules-load.d/otbr.conf so the
    kernel loads the modules on every boot:
    - pi/install.sh (curl-install) also modprobes both modules so the
    first compose up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
2026-06-21 Document the mobile-app contract + screen spec (#42)
    Workstream 6 of the deployment plan lives in a separate Flutter repo
    (smart-vent-app). This repo doesn't build the app, but it owns the
    contract — what the app talks to on the hub, and what each screen
    needs to do.
    docs/mobile-api.md
    - Hub endpoints (matter-server WS at :5580, HA REST at :8123, mDNS
    service record for discovery)
    - Auth (HA long-lived token; matter-server unauth on LAN, future
    hardening notes)
    - The three matter-server commands the app uses
    (commission_with_code, get_nodes, device_command) with request /
    response shapes and the failure-code table
    - HA REST + WS commands for Areas / Floors / entiti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
2026-06-22 Add battery carrier board design (NiMH power path for vent nodes)
    Documents an alternative power architecture using a 4-cell NiMH pack
    instead of USB: power-gated servo, battery sense, and a multi-purpose
    status LED (locate-vent first, battery/install/command-result second).
    Includes the validated SKiDL netlist, a placement-checked .kicad_pcb
    with real KiCad footprints where available, and a firmware reference
    module. Routing, three footprint sourcing gaps, and firmware wiring are
    tracked as follow-up issues (#45, #46, #47).
    [smart_vent_v1.kicad_pcb]
2026-06-22 Make the carrier board's status LED optional; commit Gerbers for pipeline validation
    Splits the carrier board into two parallel variants (with-LED and
    no-LED), generated from the same smart_vent_board.py via a
    SMART_VENT_LED toggle, so the LED can be picked based on whether the
    locate/status feedback is worth its small continuous idle draw on the
    3V3 rail. Re-verified both with KiCad: dropping the LED also resolves
    most of the worst placement cluster DRC found in #46 (3 shorts -> 1,
    8 courtyard overlaps -> 5).
    Also commits Gerber + drill exports for both (unrouted) variants,
    clearly labeled as pipeline-validation artifacts only -- not fab-ready,
    since no copper is routed yet.
    [smart_vent_v1-B_Courtyard.gbr, smart_vent_v1-B_Cu.gbl, smart_vent_v1-B_Fab.gbr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]
2026-06-22 Add .kicad_pro project files for both carrier board variants
    KiCad can open a bare .kicad_pcb without one, but without a project
    file the net-class trace/via widths from docs/battery-carrier-board.md
    §5 don't persist between sessions. Built from KiCad's blank template
    since pcbnew scripting doesn't expose project creation; pre-populates
    the Default (0.25mm) and Power (0.9mm) net classes with VBAT/VBAT_RAW/
    SERVO_VCC/GND assigned to Power.
2026-06-22 Resolve all courtyard overlaps, shorts, and clearance violations in carrier board placement
    DRC against real footprint sizes (issue #46) found the floorplan's
    exact coordinates were sized around small SMD placeholders -- the
    real stock substitutes for SW1 (THT slide switch, 10.37mm wide) and
    C2 (THT radial cap, 8.59mm round) are much bigger, causing 3 shorts +
    8 courtyard overlaps (with-LED) / 1 short + 5 overlaps (no-LED).
    Adds nudge_apart.py, an iterative courtyard-separation solver, and
    applies its resolved coordinates (plus one manual follow-up: J2's
    last pad was landing past the board's bottom edge at its original
    anchor, and separately collided with U1's placeholder footprint,
    whose t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
    [smart_vent_v1-B_Courtyard.gbr, smart_vent_v1-B_Cu.gbl, smart_vent_v1-B_Fab.gbr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]
2026-06-22 Resolve C2 footprint sourcing: Capacitor_SMD:CP_Elec_6.3x5.4 is in stock libs
    The first placement pass searched only Capacitor_THT/Capacitor_Elec
    libraries for C2's footprint and missed that the exact SMD part the
    original netlist specified is filed under Capacitor_SMD.pretty. Swaps
    it in for both variants in place of the bulkier THT radial stand-in,
    narrowing issue #45 down to two remaining placeholders (U1, J1).
    The real footprint's slightly different courtyard shape (9.69x7.19mm
    vs the THT substitute's 8.59x8.59mm round) introduced one new minor
    overlap with R2, fixed with a small nudge. DRC stays clean (0 shorts/
    overlaps/clearance) on both variants after the fix.
    [smart_vent_v1-B_Courtyard.gbr, smart_vent_v1-B_Cu.gbl, smart_vent_v1-B_Fab.gbr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]
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
